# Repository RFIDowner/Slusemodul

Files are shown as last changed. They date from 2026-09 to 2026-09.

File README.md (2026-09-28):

# Slusemodul

Modulær duesluse for PigeonPal: duene går én og én over innebygde 125 kHz RFID-spoler, slik at hver chipring leses sikkert ved hjemkomst. Alle deler printes i PETG på Bambu Lab A1 (maks 256 × 256 × 256 mm).

## Versjoner

| Versjon | Hva | Status |
|---|---|---|
| **v4.3** | **Kabelføring, kortfeste, skyvelokk løftet 4 mm, leser i tørt rom, gafler med nav** | **Gjeldende – STL og STEP klar** |
| v4.2 | Som v4.1, men 8-kantede gafler som hviler mot karkanten. Terskelstangen er fjernet. | Erstattet av v4.3. Karet er printet. |
| v4.1 | Som v4, men vegger og tak er én hette. To print totalt. | Erstattet av v4.2 |
| v4 | Ett kar (200 mm): forgang med elektronikk + rett spole, gafler, klikk-feste | Erstattet av v4.1 (kar, lokk og gafler er like) |
| v3 | Tre moduler A–M–B med svalehaleskjøt (rett spole + diamantspole) | Erstattet av v4. Modul B er printet. |
| v2 | Ett kar med to spoler og sidekammer | Kun tegning |
| v1 | Første tegning, én diamantspole | Kun tegning |

Hvorfor v4: diamantspolen i v3 er 141 mm lang langs løpet, så to duer kunne stå i lesesonen samtidig. Den rette spolen er 100 mm, og forgangen foran holder neste due utenfor lesesonen.

## v4.3 – gjeldende modell

Erfaring fra v4.2-printen: klikk-nesene som holder spolen er perfekte og er uendret. Endringene:

- **Lokket** under el-rommet er løftet 4 mm over brettet, så det aldri står i vann. Det skyves inn fra inngangsenden i spor (kile under og skinne over, begge med 45° så de printes uten støtte) og låses med en klikk-tunge bak endeveggen. Fingerhull Ø7 i tungen: løft tungen og dra. Tre dreneringsslisser ved skilleveggen. Ingen skruer, ingen pakning.
- **Leseren** (35 × 15 × 1 mm) sitter i tørt rom, i en holder i hjørnet ved skilleveggen. Den skyves inn mot skilleveggen og holdes av en liten kul. Kabler ut i begge ender.
- **Skilleveggen** har to slisser, begge åpne nedenfra: 2 mm sprekk for spoletrådene rett foran leserens ende, og 5 mm slisse for strømkabelen. Tettes med Sika etter at kablene er lagt. Det er de eneste åpningene inn i el-rommet.
- **Strømkabelen** kommer inn under sideveggen gjennom en slisse 5 × 6 mm i underkanten, rett etter skilleveggen. PG7-hullet er borte.
- **PigeonPal-PCB** henger under gulvet på tre avstandsklosser med styretapper i H4, H3 og H1 (mål fra KiCad-filen), og holdes av to fjærende kroker. Komponentsiden vender ned mot lokket. Pluggkanten (J9, J3, J4) vender mot −y med 55 mm fri plass foran pluggene. Bøy krokene ut for å ta av kortet.
- **Gaflene** har en 8-kantet nav på 21 mm langs akselen. Fem naver fyller 105 av 110 mm, så de holder avstanden selv med 1 mm mellom hver. Stangen ligger flush med navet på utsiden, så gaffelen ligger flatt i printen.
- **Fjernet:** ribbene under leseren (107 mm broer i printen, ingen funksjon) og det blinde Ø6-hullet i skilleveggen.
- Slissene for veggtappene har runde ender.

| Print | Fil | Mål på platen |
|---|---|---|
| 1 | `stl/v4.3/sluse_v4.3_print1_kar_og_gafler.stl` – kar (gulvet ned) + 5 gafler | 200 × 239 × 32 mm |
| 2 | `stl/v4.3/sluse_v4.3_print2_hette_og_lokk.stl` – hette (taket ned) + lokk (oversiden ned) | 200 × 230 × 133 mm |

Sammenstillingen `step/v4.3/sluse_v4.3_sammenstilling.step` har kortet, leseren, spolen og akselen som referanser. Bilder i `tegninger/v4.3/`. Generator: `generator/sluse_v4_3_step.py`.

Ikke testet på print: lokkets spor (0,3 mm klaring), klikk-tungen, krokene på kortet og leserholderen (0,15 mm kul).

## v4.2 – 8-kantede gafler mot karkanten (erstattet av v4.3)

Som v4.1, med to endringer i utgangen:

- **8-kantede gafler**, 6 mm over flatene, med et rundt øye (Ø9) rundt akselen. De printes liggende på en flate, uten støtte.
- **Karkanten er stopperen.** Akselen står der den var (x = 188, 116 mm over gulvet). Gaflene henger ca. 7° på skrå fra akselen og ut over karets endekant. Endekanten har en skråflate (1,2 mm inn i toppen, 10 mm ned) som gaflene ligger flatt mot. Gaflene går 2 mm lenger ned enn skråflaten. Terskelstangen er fjernet.
- Kontrollert i modellen: gaflene stopper mot karet med en gang de dyttes utover, og kan svinge ca. 80° innover i slaget før de treffer taket.

| Print | Fil | Mål på platen |
|---|---|---|
| 1 | `stl/v4.2/sluse_v4.2_print1_kar_og_gafler.stl` – kar (gulvet ned) + 5 gafler | 200 × 219 × 32 mm |
| 2 | `stl/v4.2/sluse_v4.2_print2_hette_og_lokk.stl` – hette (taket ned) + lokk | 200 × 227 × 133 mm |

Bilder: `tegninger/v4.2/`. Generator: `generator/sluse_v4_2_step.py`.

## v4.1 – vegger og tak som én hette (erstattet av v4.2)

Samme kar, lokk, gafler og terskelstang som v4. Endringen er at begge veggene og taket er smeltet sammen til **én hette**. Den printes opp-ned: taket ligger på platen og veggene står rett opp.

| Print | Fil | Mål på platen |
|---|---|---|
| 1 | `stl/v4.1/sluse_v4.1_print1_kar_og_gafler.stl` – kar (gulvet ned) + 5 gafler + terskelstang | 200 × 224 × 32 mm |
| 2 | `stl/v4.1/sluse_v4.1_print2_hette_og_lokk.stl` – hette (taket ned) + lokk | 200 × 227 × 133 mm |

- Hetta klikkes ned i karet med de samme tre tappene per vegg som i v4. Klikket mellom tak og vegg er borte.
- Veggfoten er 12 mm bred (var 20 mm) med 45° skråkant, slik at den kan printes uten støtte når hetta står opp-ned.
- Hetta er 133 mm høy på en bedslinger. U-formen er stivere enn to løse vegger, men bruk gjerne brim og litt lavere hastighet på yttervegg.
- Delene finnes også hver for seg i `stl/v4.1/` og `step/v4.1/`, og samlet i `step/v4.1/sluse_v4.1_sammenstilling.step`.
- Bilder: `tegninger/v4.1/`. Generator: `generator/sluse_v4_1_step.py`.

Ikke testet på print ennå: klaringene på klikk-tappene. Mothaken på tappene har en 0,9 mm flat kant som blir et lite overheng i print 2, men det er for kort til å trenge støtte.

## v4 – ett kar, løse vegger og tak (erstattet av v4.1)

Ett kar på 200 × 150 mm, gulvet 32 mm over landingsbrettet:
- **Forgang (0–90 mm):** elektronikkammer under gulvet. Lokk fra undersiden med fire M3-skruer og spor for Ø2 silikonsnor. Hull i sideveggen for PG7-kabelnippel.
- **Leser (90–200 mm):** rett 10 × 10 cm-spole i lomme under 4 mm gulv. Spolen presses opp nedenfra, og fire fjærende klikk-neser holder den. Kabelen går inn i kammeret gjennom et hull høyt i skilleveggen.
- **Gafler i utgangen:** fem Ø6 × 116 mm som henger til 3 mm over gulvet mot en terskelstang på slusesiden. De svinger bare innover.
- **Klikk-feste uten skruer:** veggene har tre tapper hver ned gjennom gulvet i spoledelen. Taket klikker inn i et spor på utsiden av veggenes topplist.

| Fil | Innhold |
|---|---|
| `stl/v4/` | Kar, lokk, vegg høyre/venstre, tak, gafler + terskel. Print-orientert, ingen støtte. |
| `step/v4/` | Samme deler i montert posisjon, og `sluse_v4_sammenstilling.step` med alt samlet (inkl. spole og aksel som referanse). |
| `tegninger/v4/` | Bilder av montert modell og undersiden. |
| `generator/sluse_v4_step.py` | Lager alle v4-filene (krever `pip install cadquery`). |

Kjøpedeler: aksel Ø3 × 130 mm rustfri, Ø2 silikonsnor, 4 × M3 × 8 mm skruer til lokket.

Ikke testet på print ennå: klaringene på klikk-festene (standardverdier for PETG) og at klikk-nesene passer spolen (dimensjonert for nøyaktig 100 × 100 mm ytre mål).

Mulig endring senere: la gaflene henge utenfor karets endevegg, slik at karkanten blir stopperen og terskelstangen kan fjernes.

## v3 – tre moduler (erstattet av v4)

Slusa består av tre moduler som skyves sammen ovenfra med svalehaleskjøt:

| Modul | Lengde | Innhold |
|---|---|---|
| **A** – inngang | 110 mm | Rett 10 × 10 cm-spole, trådene på tvers av løpet |
| **M** – midt | 90 mm | Elektronikkammer under gulvet (PigeonPal-PCB + to lesermoduler), lokk fra undersiden |
| **B** – utgang | 150 mm | Diamantspole (dreid 45°) + bobs som bare svinger innover |

- Løpet er 110 mm innvendig bredde og 120 mm åpningshøyde. Gulvet ligger 32 mm over landingsbrettet.
- Vegger og tak er spiler, så slusa er gjennomsiktig og ikke oppleves som en tunnel.
- De to spolene har ulik orientering (rett og diamant), så de feiler på forskjellige ringvinkler. Det gir reell redundans, ikke bare dobbelt opp.
- Rekkefølgen A → B gir retning. Firmware dedupliserer samme chip-ID fra begge portene (J3/J4).
- Elektronikken ligger i en modul uten spole, minst ca. 5 cm fra nærmeste vikling.

Bakgrunnen for høydevalget (ring 9–14 mm over viklingen, ikke 5–10 cm) står i [`analyse/coil-hoyde-rapport.md`](analyse/coil-hoyde-rapport.md).

## Status (v3-deler)

| Del | Status |
|---|---|
| Modul B – kar med diamantlomme | STL klar, testprint pågår |
| Modul B – veggpanel høyre/venstre | STL klar |
| Modul B – takpanel | STL klar |
| Modul B – bobs, stoppstang, sperrelister | ikke laget ennå |
| Hele v3 (A + M + B) som STEP, tre bodies | klar |
| v4 – ett kar, klikk-feste, gafler | STL og STEP klar |
| Modul A og M – printbare delfiler | ikke laget ennå |
| Klikk-/snapp-feste i stedet for skruer | planlagt |

## Mapper

- `stl/modul_B/` – ferdige STL-filer, allerede lagt i print-orientering (ingen støtte).
- `step/` – STEP-filer til Fusion, i montert posisjon:
  - `sluse_v3_komplett_3_bodies.step` – hele slusa, der A, M og B er hver sin body (kar, vegger og tak smeltet sammen per modul).
  - `sluse_v3_modul_*.step` – én modul per fil.
  - `step/modul_B/` – modul B delt opp i de fire delene som printes (kar, vegg høyre/venstre, tak), og en sammenstilling.
- `generator/` – Python-skript som lager STL-ene. Alle mål er parametre øverst i hver fil.
- `tegninger/v1…v3/` – tekniske tegninger (SVG/PNG) og skriptene som lager dem.
- `analyse/` – rapport om spolehøyde og lesesikkerhet, med Biot–Savart-modellen av spolen.

## Lage STL på nytt

```bash
pip install manifold3d numpy
python generator/modul_B_kar.py
python generator/modul_B_vegg.py
python generator/modul_B_tak.py
```

STL-ene skrives til `stl/modul_B/`. STEP-filene lages med `generator/modul_B_step.py` og `generator/sluse_v3_step.py` (krever `pip install cadquery`). Forhåndsvisninger (SVG) havner i samme mappe, men holdes utenfor git.

## STEP i Fusion

- **Som eget design:** File → Open → Open from my computer → velg `.step`.
- **Inn i et design du jobber med:** last opp filen i Data Panel, høyreklikk den og velg **Insert into Current Design**.
- Modellene kommer inn som solider uten parametre. Bruk Press/Pull, skisser og Combine for å endre dem.

## Print-innstillinger (PETG, A1)

- 0,20–0,28 mm lag, 2 vegger, 10–15 % infill.
- Skjørt, ikke brim.
- Ingen støtte: alle deler er orientert slik at hulrom og lommer åpner oppover.
- Legg inn raskere hastigheter enn Generic PETG-profilen, for eksempel yttervegg 120 mm/s og indre vegg 200 mm/s.

## Kjøpedeler

- Bobs-aksel: Ø3 × 150 mm, rustfri eller messing. Ikke vanlig stål nær spolene.
- Treskruer 3,5 × 25 mm til veggføtter og feste mot landingsbrettet.
- Skruer 3 × 12 mm til takpanel.
- Kabelnippel eller Ø2 silikonsnor til pakning i modul M.

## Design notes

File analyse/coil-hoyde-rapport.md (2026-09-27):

# Chipring-lesing i duefelle: lav eller hevet spole?

## 1. Kort svar

**Ikke bygg forhøyningen.** Monter spolen rett under et tynt gulv slik at ringen passerer 0,5–2 cm over viklingen (alternativ A). Det er teoretisk klart sterkest, og konklusjonen A > B gjelder uansett hvilken vei transponderaksen i ringen peker. Å legge spolen 5–10 cm under fuglen (alternativ B) flytter ringen til den delen av feltet der du målte *maks* rekkevidde på benken, dvs. null margin: 8–10 cm er lesegrensen for beste orientering på spoleaksen, ikke en driftshøyde. For en ring med horisontal transponderakse er 7–10 cm under terskel for alle ringrotasjoner (0,36–0,80× terskel i modellen), og 5 cm er marginalt. Det beste svaret er likevel ikke bare "lavt", men "lavt pluss riktig spolegeometri", se punkt 4.

## 2. Teorien, punkt for punkt

Alle tall er fra en Biot–Savart-modell av din 10 × 10 cm luftspole (ren Python, `coil_field_biot_savart.py` i denne mappen), verifisert mot lærebokformelen for senterfeltet (2√2·μ0·I/(π·a) = 11,31 µT per ampere-vikling). Terskelen er kalibrert fra din benketest: B_thr = feltet på aksen ved 9 cm = 14,6 % av senterfeltet. Absoluttverdiene skalerer med N·I; alle *forhold* (marginer, lesbar lengde) er uavhengige av det.

**a) Feltstyrke mot høyde.** På aksen er feltet nesten flatt så lenge høyden er mye mindre enn halvbredden (5 cm): 99 % av senterverdien ved 0,5 cm, 95 % ved 1 cm, 83 % ved 2 cm, 68 % ved 3 cm, 41 % ved 5 cm, 24 % ved 7 cm, 19 % ved 8 cm, 11,5 % ved 10 cm, deretter mot 1/z³ (Microchip AN678: feltet faller som r⁻³ og er hovedbegrensningen for rekkevidde). Ved 0,5–1 cm ligger vertikalfeltet 6,5–6,8× over terskelen (ca. 16 dB; 5,1–5,3× hvis reell grense er 8 cm). Ved 5–10 cm er du på den delen av kurven som faller med eksponent −1,6 (5–7 cm), −1,9 (7–8 cm) og −2,1 (8–10 cm), på vei mot −3. AN678/AN710s optimumsregel (sløyferadius ≈ 1,414 × leseavstand) sier bare at ved 8–10 cm ville en 14–28 cm bred sløyfe gitt mer felt per ampere-vikling; 10 cm-spolen leser der (det viser testen din), men den jobber utenfor sitt optimum, uten margin.

**b) Feltretning mot høyde og sideveis posisjon.** Inne i sløyfen nær overflaten er feltet vertikalt; rett over en leder er det horisontalt og sirkulært rundt tråden (≈ μ0·N·I/(2π·d), 1/d-lov). Rett over spolens senter er horisontalkomponenten *eksakt null i alle høyder* (symmetri). Feltets helning fra vertikal rett over tråden: 84° ved 0,5 cm, 78° ved 1 cm, 67° ved 2 cm, 59° ved 3 cm, 48° ved 5 cm, 40° ved 7 cm, 33° ved 10 cm. Jo høyere du går, desto mer *vertikalt* blir feltet også over trådene, og horisontalmaksimum flytter seg utover (5,5–6,5 cm fra senter ved 7–10 cm) og krymper til ~0,5× aksefeltet i samme høyde. Høyde gir altså ingen orienteringsgevinst for en fotring; forholdet horisontal/vertikal er låst til ~0,5 for alle høyder ≥ 3 cm.

**c) cos-θ-kobling og fotringen.** Indusert spenning i tag-spolen er V = 2πf·N·S·Q·B·cos α (AN678/AN710): bare feltkomponenten *langs transponderaksen* teller. Hvor aksen peker inne i ringen er avgjørende:
- *Horisontal akse* (typisk Hitag S-modul 8 × 10 mm i "knollen", radial eller tangential): ringen kobler kun til horisontalfeltet, som finnes bare nær lederne. Dette er det PIT-/fiskeri-litteraturen kaller "pass-over"-geometri: taggen leses best rett over tråden, rekkevidden er kortere enn "pass-through", og to separate deteksjoner per passering er mulig (Oregon RFID; LF 125 kHz-studien av steinsporing: "i vinkelrett konfigurasjon er deteksjonen svak, taggen kan bare detekteres over antennens kanter"). Ringen roterer fritt rundt beinet, så azimut er tilfeldig per passering. En ring hvis akse tilfeldigvis står *på tvers* av gangretningen og går nøyaktig på midtlinjen ser By = 0 i alle høyder. Det er et geometriproblem, ikke et høydeproblem.
- *Vertikal akse* (spole viklet rundt ringens omkrets, jf. EP2036001): ringen kobler til vertikalfeltet, hele sløyfeinteriøret er lesesone, og benketesten er direkte representativ.
- Beinet (tarsometatarsus) står ikke loddrett, anslagsvis 20–40° fra vertikal i stående stilling og mer under steget. Med 30° helning får en "horisontal-akse"-ring en Bz-kobling på ca. 0,5·Bz, som i praksis fjerner azimut-nullet i alternativ A, gjør 5 cm marginalt lesbart for alle rotasjoner og lar 7–10 cm forbli under terskel.

**d) Margin: dypt inne i feltet vs. nær maks rekkevidde.** Realistisk minsteavstand transponder–leder er 1–2 cm (viklingsbunt 2–5 mm + gulv 3–10 mm + knollens høyde over sålen), 1,5–3 cm i standfasen og 3–5 cm i svingfasen. 0,5 cm-raden under er en teoretisk grense, ikke driftspunktet. Overkobling/detuning ved lav høyde er ikke et problem for en mm-stor fotringtransponder: k ≈ 0,01 over tråden mot kritisk kobling k_c = 1/√(Q1·Q2) ≈ 0,05, dvs. ≥ 4× underkoblet, ingen frekvenssplitting (PMC5017394). Både energioverføring og lastmodulasjon tilbake til leseren skalerer med samme gjensidige induktans, så nærmere ring forbedrer begge samtidig.

| Avstand ring–vikling | Vertikal akse: margin på aksen | Vertikal akse: lesbar lengde av 18 cm | Horisontal akse, beste rotasjon: margin over leder | Horisontal akse, verste rotasjon m/ 30° beinhelning | Horisontal akse, beste rotasjon: lesbar lengde |
|---|---|---|---|---|---|
| 0,5 cm (teoretisk) | 6,8× | hele | 24× | – | 9 cm (to bånd) |
| 1 cm | 6,5× | hele | 11,8× | 4,5× | 11 cm (to bånd) |
| 2 cm | 5,7× | 13,5 cm | 5,5× | 2,9× | 14 cm |
| 3 cm | 4,7× | 11,5 cm | 3,3× | 2,3× | 14 cm |
| 5 cm | 2,8× | 11,5 cm | 1,5× | 1,4× | 11 cm |
| 7 cm | 1,65× | 9,5 cm | 0,80× | 0,8× | 0 |
| 8 cm | 1,28× | 7,5 cm | 0,61× | – | 0 |
| 10 cm | 0,79× | 0 | 0,36× | – | 0 |

Ved 0,5–1 cm er lesesonen for horisontal akse *to* 4,5–5,5 cm brede bånd sentrert på de to tverrtrådene (ca. 2,6–7,6 cm fra senter ved 1 cm), med et null over senteret. Gangbane 2,5 cm ut av senter gir lengre lesbar sone (opptil 17,5 cm ved 2–3 cm) fordi sidetrådene bidrar med By. Forhold lav/høy for horisontal akse: 1 cm mot 5/7/8/10 cm = 7,8× / 15× / 20× / 33×, dvs. 18–30 dB kastet bort uten noen orienteringsgevinst. Ved 7–10 cm er beste horisontalfelt 0,36–0,80× terskelen; med modellens usikkerhet (±1,27×) er 7 cm "ikke pålitelig", 8–10 cm "ikke lesbar". Ved 5 cm faller omtrent halvparten av ringrotasjonene under terskel uten beinhelning.

**e) Oppholdstid og telegramrepetisjon.** EM4100/TK4100 sender 64 bit kontinuerlig ved RF/64: 64 × 512 µs ≈ 33 ms per telegram, ≤ 66 ms sammenhengende felt garanterer ett komplett telegram (RDM6300 leverer pakke hvert ~65 ms). Er leseren en RDM6300/EM4100-modul, er ringene EM4100/TK4100-kompatible; Hitag S (kommandostyrt, T0 = 8 µs, anslått samme størrelsesorden fra T0/twsc, ikke målt full lesesyklus) gjelder da ikke. Duer på tredemølle er kjørt ved 0,20–0,40 m/s (JEB 209:292); løp begynner rundt 0,75–0,9 m/s (Gatesy & Dial 1993; Fujita 2002). Men gangen er ikke jevn: foten står stille i standfasen (~0,25 s) eller svinger 2–4 cm over gulvet i ~0,15–0,2 s, ca. dobbelt så fort som kroppen. Med ett 10 cm-kvadrat og to lesebånd 10 cm fra hverandre er det grovt ~1/3 sjanse for at ingen stans havner i et bånd (horisontal akse); da må ringen leses i svingfasen ved 3–4 cm (2–3× margin, 60–80 ms = 1–2 EM4100-telegram, knapt for en Hitag S-handshake). Tid er ikke flaskehalsen, men sammenhengende lesesoner (vertikal akse, figur-8 eller flere ledere på tvers) er å foretrekke, nok et argument mot forhøyning.

**f) Kommersiell praksis.** Benzing G2 (15 × 19 cm per felt), Bricon (1–6 felt) og Unikon ("two-field pad") er flate flerfeltspader i 22–27 mm tykke hus, montert i eller under ≤ 15 mm kryssfiner (Bricon); ringen passerer derfor typisk 2–4 cm fra viklingen, innenfor sonen der modellen gir 3–5× margin, aldri 5–10 cm. FCI krever sikker lesing innenfor 5 cm. At Bricons "5–7 cm"-test er en marginkontroll med håndholdt ring og ikke driftshøyde, er vår tolkning, ikke leverandørens ord.

## 3. Hva benketesten sier, og ikke sier

Den sier hvor terskelen ligger for beste orientering (≈ 0,12–0,19 × senterfeltet) og at leser + spole + ring fungerer. På spoleaksen er feltet rent vertikalt. At ringen leses på aksen ved 8–10 cm betyr derfor at transponderaksen hadde en vesentlig vertikal komponent *i testorienteringen*. Hvordan holdt du ringen?

- Holdt du den **flatt, slik den sitter på beinet** (ringplanet parallelt med spolen): da er aksen vertikal på fuglen, benketesten er direkte representativ, og Bz-kolonnen gjelder. A gir 6–9× margin over hele sløyfen; B ved 5 cm gir 2,8× og fungerer, men 7,7 dB dårligere og uten reserve for høydevariasjon; 8 cm 1,28×, 10 cm ingen lesing. Figur-8/skjevstilling er da ikke nødvendig.
- Holdt du den **på høykant / med knollen flatt** (aksen horisontal på beinet): da gjelder kant-/pass-over-analysen, og geometrivalg i punkt 4 blir nødvendig, ikke valgfritt.

Testen sier ikke noe om gangfart, beinhelning, ringrotasjon eller om foten faktisk krysser en leder. Bruk 8–10 cm kun som terskelreferanse, aldri som driftshøyde.

## 4. Anbefaling, rangert

**Felles for alle:** spole rett under gulvet. 3–10 mm PETG er fint (Bricon tillater 15 mm kryssfiner); det som teller er total avstand ring–vikling ≤ 2–3 cm. Ingen metall, folie, netting eller karbonfylt plast mellom spole og fot (skinndybde 0,2–0,26 mm i Cu/Al ved 125 kHz gir titalls dB skjerming pluss detuning). Spolen bør være minst like bred som gangbanen (10–12 cm), så enten 12–14 cm sløyfe eller to sløyfer side om side. Lag et kort kanalløp så fuglen må *gå* over spolen, ikke hoppe; hopp over paden er den vanligste feilårsaken i praksis. Hold leser og evt. andre 125 kHz-spoler ≥ 1 m fra hverandre.

1. **Lav montering + ledere langs OG på tvers av gangbanen** (høyest sikkerhet, middels innsats). Kvadratisk sløyfe kombinert med en langsgående figur-8 (byttet/multiplekset, eller to leserkanaler): verste-azimut-margin 10,8× / 5,0× / 3,0× ved 1/2/3 cm. Alternativt kvadrat + liten vertikal veggspole (akse på tvers av passasjen) for tverr-azimuten. Merk: figur-8 med felles midtleder *på tvers* dobler feltet over midtlederen (79/39/18/11/5 µT per A-vikl. ved 0,5/1/2/3/5 cm, ved lik strøm per sløyfe) og flytter nullet til ytterkantene, men fjerner ikke tverr-azimut-nullet på midtlinjen. Induktansen omtrent dobles, så ved samme drivspenning blir gevinsten mindre og leseren må tunes på nytt. Patent 5602556 (figur-8 gir felt parallelt med antennen) og 8558751 (dobbel sløyfe med alternerende fase mot orienteringsvarians, 125 kHz) beskriver prinsippet.
2. **Lav montering + én sløyfe dreid 45° ("diamant") eller 15–30° skjev**, minst tre ledere på tvers av banen (best nytte/innsats). Diamant: verste-azimut 7,9× / 3,2× / 1,7× ved 1/2/3 cm for et bein 2 cm fra midten, 4,1× / 1,1× / 0,5× 0,5 cm fra midten og null eksakt på midtlinjen, men 5,3× / 3,0× / 2,3× også på midtlinjen med 30° beinhelning. Chipringen sitter på ett bein ca. 1–1,5 cm fra kroppens midtlinje, og fuglen vandrer, så midtlinje-nullet er lite i praksis, men ikke null. Forskyvning 2,5 cm fra midtlinjen gir tverr-azimut-dekning, men bare 0,8× / 1,4× / 1,8× / 1,6× margin ved 0,5/1/2/3 cm, ikke tilstrekkelig alene.
3. **Lav montering + én kvadratisk sløyfe sentrert, trådene på tvers** (enklest). To 4,5–5,5 cm brede lesebånd med 9–12× margin (beste rotasjon), men ~5–15 % av rotasjonene bommer på midtlinjen ved 0,5–2 cm, og ~1/3 av passeringene får ingen stans i et bånd. Godt nok hvis aksen viser seg å være vertikal.
4. **Vertikal portalsløyfe fuglen går gjennom**, ca. 12 × 18 cm: svært høydetolerant (10 × 10-modellen ga 45/25/15,5/12,7/11,3 µT per A-vikl. ved 0,5–5 cm over gulvet) og orienteringsrobust for akse langs gangretningen; mer mekanikk og trenger sidespole for tverr-aksen.
5. **Forhøyet gangbane, spole 5–10 cm under (B):** dårligst. Horisontal akse: null lesing ved ≥ 7 cm, marginalt ved 5 cm. Vertikal akse: 2,8× ved 5 cm, 1,28× ved 8 cm, ingen ved 10 cm, alt uten reserve for høydevariasjon. Ikke anbefalt.

## 5. Benketest du kan gjøre i kveld

**Test 0 (5 min, avgjør aksen):** sett ringen på en vertikal pinne nøyaktig som på beinet (ringplanet horisontalt). Senk den til 1 cm over spolens *senter* og over en *kanttråd*. Leser bare over kanten → horisontal akse, punkt 4.1–4.2 er nødvendig. Leser best over senter → vertikal akse, punkt 4.3 holder.

**Test 1 (høydeskann):** samme pinne, beveg ringen horisontalt tvers over spolen i fast høyde 0,5 / 1 / 2 / 3 / 5 / 8 cm over viklingen, sentrert bane og bane 2,5 cm ut av senter. Noter hvor den leser. Gjenta med ringen rotert 0°, 45° og 90° om pinnen.

Forventet (horisontal akse): ved 0,5–1 cm to smale bånd (4–6 cm) over trådene, null i midten; ved 2–3 cm bredere men svakere bånd; ved 5 cm sporadisk, avhengig av rotasjon; ved 8 cm ingenting. Forventet (vertikal akse): lesing over hele sløyfen ved 0,5–3 cm, krympende mot 7–8 cm, ingenting ved 10 cm. Forskjøvet bane bør gi lengre lesesone ved 1–3 cm.

**Det som bekrefter anbefalingen:** sikker lesing ved 1–3 cm (over trådene eller hele flaten) og tap ved 5–8 cm. **Det som velter den:** sikker lesing i alle rotasjoner ved 5–8 cm og *ikke* ved 1–2 cm; da er enten viklingen mye bredere/spolen tunet slik at nærsonen overkobler (front-end-problem, løses med Q/tuning), eller premissene om ringen er feil, og vi må se på den på nytt.

**Etter bygging:** test med aluminiums-forbundsringen montert som på fuglen, og logg med levende fugl i gangfart, ikke bare ringen på pinne; fotplassering i standfasen er den gjenværende feilkilden. Krav: sammenhengende lesing over ≥ 4 cm i alle rotasjoner ved faktisk gulvhøyde.

## 6. Usikkerheter

- Transponderaksen i ringen er ukjent; Test 0 avgjør. A > B holder i begge tilfeller, men geometrikravene avhenger av det.
- Modellen er en filamentær enkeltvikling i luft, uten gulv-/kroppstap. 40 µT-toppen ved 0,5 cm er overestimert for en flere mm bred viklingsbunt; verdiene ved 1–3 cm er robuste. En bunt av bredde w flater ut 1/d-loven for d < w.
- Terskel kalibrert til 9 cm; 8 cm krymper alle marginer 1,28×, 10 cm øker dem 1,26×. Ingen konklusjon endres.
- Beinhelning (20–40°), ringens vagging, eksakt beinhøyde over gulvet og stegmønster er antatt, ikke målt.
- Transpondertype (EM4100 vs Hitag S) påvirker telegramtid og H_min, ikke høydetrenden. Hitag S-timing er et estimat fra datablad-utdrag.
- Leserens følsomhet, Q og AGC kan gi egne nærsone-effekter; det er et front-end-problem, ikke et høydeproblem.
- Ingen sitater kunne verifiseres mot originaldokumentene i denne kontrollen (nettsperre); ordlyd fra Microchip, Oregon RFID, patenter, Bricon/Benzing/Unikon, FCI og tidsskrifter bør sjekkes mot PDF-ene før den siteres videre.

## 7. Kilder

- [Microchip AN678, RFID Coil Design](https://ww1.microchip.com/downloads/en/appnotes/00678b.pdf) – r⁻³-fall, cos α-kobling, optimumsregel for sløyferadius
- [Microchip AN710, Antenna Circuit Design for RFID Applications](https://ww1.microchip.com/downloads/en/appnotes/00710c.pdf)
- [Microchip DS51115, microID 125 kHz Design Guide](https://ww1.microchip.com/downloads/en/devicedoc/51115f.pdf)
- [OpenStax, Magnetic Field of a Current Loop](https://phys.libretexts.org/Bookshelves/University_Physics/University_Physics_(OpenStax)/University_Physics_II_-_Thermodynamics_Electricity_and_Magnetism_(OpenStax)/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) – Biot–Savart, aksefelt
- [IntechOpen, LF/HF RFID coupling and H_min](https://www.intechopen.com/chapters/57275)
- [Finkenzeller, RFID Handbook, 3. utg.](https://www.wiley.com/en-us/RFID+Handbook:+Fundamentals+and+Applications+in+Contactless+Smart+Cards,+Radio+Frequency+Identification+and+Near+Field+Communication,+3rd+Edition-p-9780470695067)
- [Oregon RFID, Antenna types (pass-over vs pass-through)](https://www.oregonrfid.com/resources/antenna-types/)
- [Biomark PIT-tag antennas](https://www.biomark.com/pit-tag-antennas/) og [AFS/Biomark antenner](https://units.fisheries.org/fits/solution/fish-tracking/rfid/biomark-antennas/)
- [NOAA, PIT-antenne feltgeometri](https://repository.library.noaa.gov/view/noaa/50485/noaa_50485_DS1.pdf)
- [Zentner et al. 2021, PIT-antenne deteksjon vs orientering](https://agriculture.okstate.edu/departments-programs/natural-resource/research/natural-resource-labs/shoup-fisheries-management-and-fisheries-ecology-lab/zentner_et_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)
- [Pebbles tracking with LF RFID multi-loop reader (kantdeteksjon i vinkelrett orientering)](https://www.researchgate.net/publication/270337982_Pebbles_Tracking_Thanks_to_RFID_Lf_Multi-Loops_Inductively_Coupled_Reader) / [HAL](https://centralesupelec.hal.science/hal-01104660)
- [US 5602556, figur-8-sløyfe med felt parallelt med antennen](https://image-ppubs.uspto.gov/dirsearch-public/print/downloadPdf/5602556)
- [US 8558751, dobbel sløyfe med alternerende fase, 125 kHz](https://image-ppubs.uspto.gov/dirsearch-public/print/downloadPdf/8558751)
- [PMC5017394, kritisk kobling og frekvenssplitting](https://pmc.ncbi.nlm.nih.gov/articles/PMC5017394/)
- [EP0884700B1, Deister/Unikon flerfelts duepad](https://patents.google.com/patent/EP0884700B1/en)
- [EP2036001B1, transponder-fotring for duer](https://patents.google.com/patent/EP2036001B1/de)
- [FCI, krav til elektronisk konstatering](https://img.pigeonsfci.net/uploads/files/20241104/87de9a8ee1972ad0ccb38cbf030db2be.pdf)
- [Benzing G2 antenne](https://www.benzing.cc/benzing-g2-antenna/) og [Benzing antennepader](https://www.benzinguk.com/product-category/antenna-pads/)
- [Bricon Speedy manual](https://www.bricon.be/uk/manuals/Speedy%20UK-14.pdf) / [manualslib](https://www.manualslib.com/manual/1304348/Bricon-Speedy.html)
- [Unikon loft-system](https://www.unikon.co.uk/loft/) og [Unikon manual](http://www.unikon-usa.com/us/files/unikon_manual_010307.pdf)
- [Hitag S256 duefotring](https://zdcard.en.made-in-china.com/product/pSImxjvKbuYM/China-RFID-Racing-Pigeon-Foot-Ring-Hitag-S256-for-Tauris-Ets-Clocking-System.html)
- [EM4100 datablad](https://download.mikroe.com/documents/accessories/rfid/125khz/rfid-card-125khz-em4100-datasheet.pdf) og [EM4100-protokoll](https://www.priority1design.com.au/em4100_protocol.html)
- [RDM6300 (Tasmota-dok.)](https://tasmota.github.io/docs/RDM6300/)
- [NXP Hitag S datablad](https://media.digikey.com/pdf/Data%20Sheets/NXP%20PDFs/HTS.pdf)
- [J. Exp. Biol. 209:292, duer på tredemølle 0,20–0,40 m/s](https://journals.biologists.com/jeb/article/209/2/292/16277/Influence-of-the-behavioural-context-on-the)
- [Skinndybde-kalkulator](https://www.firgelliauto.com/blogs/engineering-calculators/skin-depth-calculator) og [RFID-skjerming](https://rfid4u.com/rfid-shielding-and-blocking-materials/)
- [pigeons.biz, installasjon av elektronisk klokke](https://www.pigeons.biz/threads/electric-clock-installation.65274/)

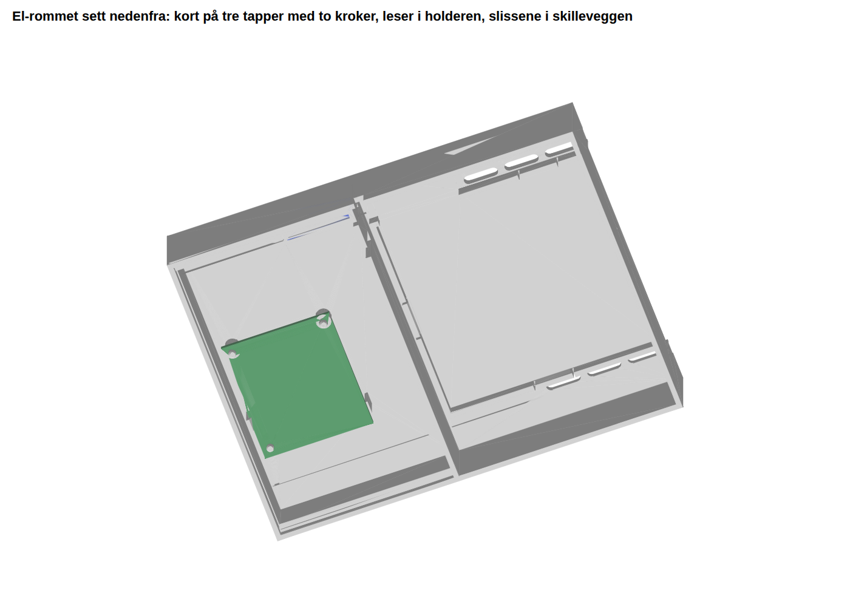
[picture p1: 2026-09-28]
tegninger/v4.3/sluse_v4.3_kammer_naerbilde.png

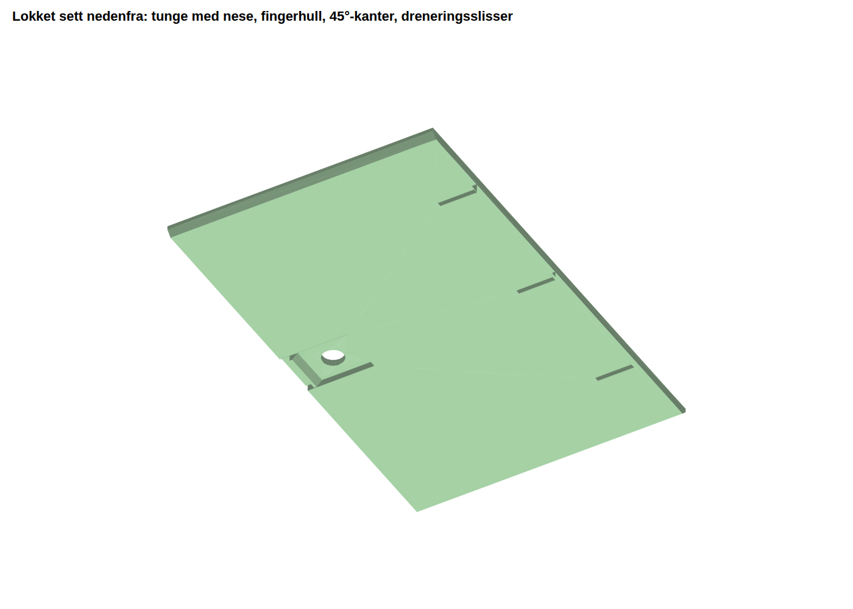
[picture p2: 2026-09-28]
tegninger/v4.3/sluse_v4.3_lokk.png

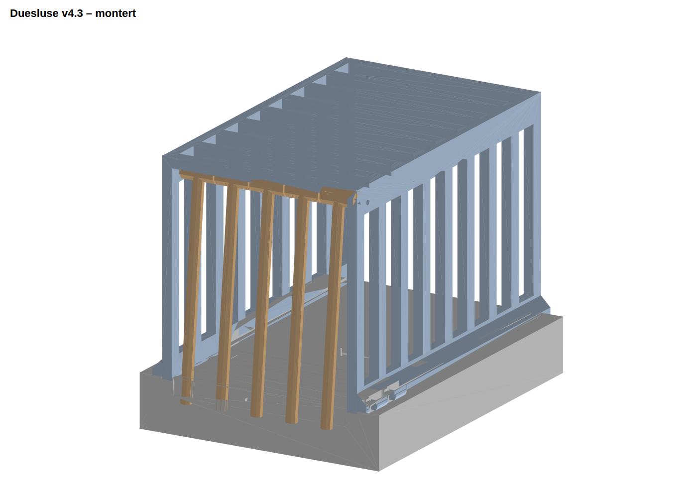
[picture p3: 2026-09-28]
tegninger/v4.3/sluse_v4.3_montert.png

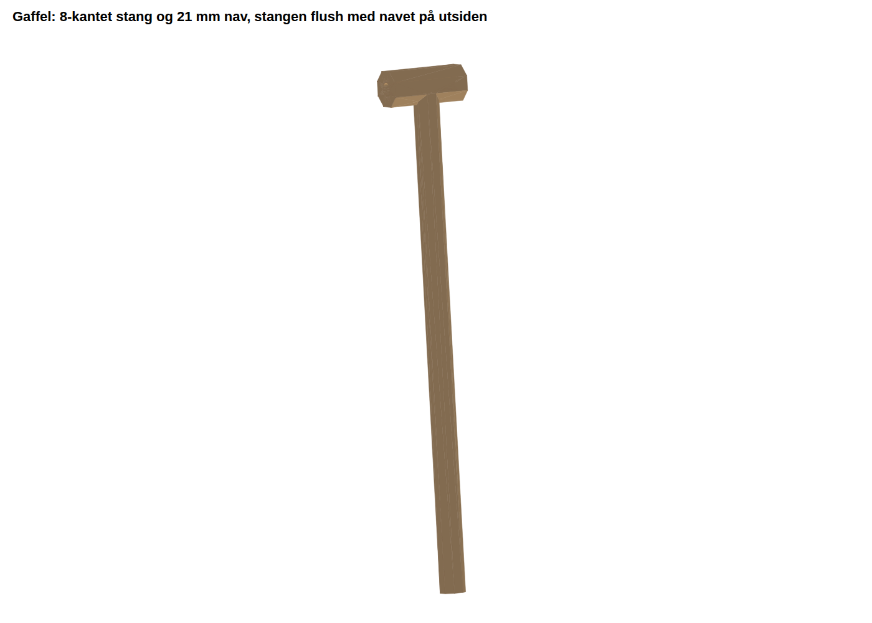
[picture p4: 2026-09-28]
tegninger/v4.3/sluse_v4.3_gaffel.png

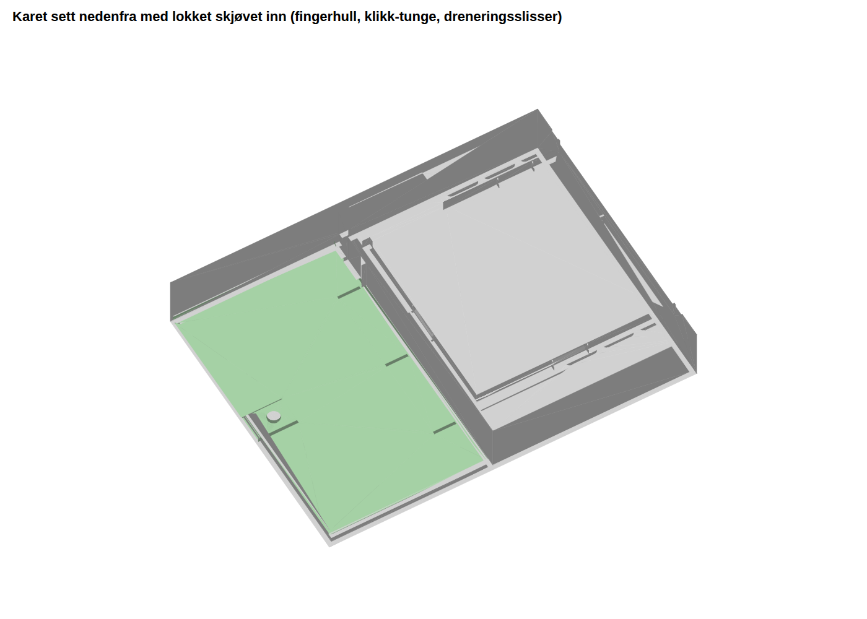
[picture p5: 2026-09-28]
tegninger/v4.3/sluse_v4.3_kar_med_lokk.png

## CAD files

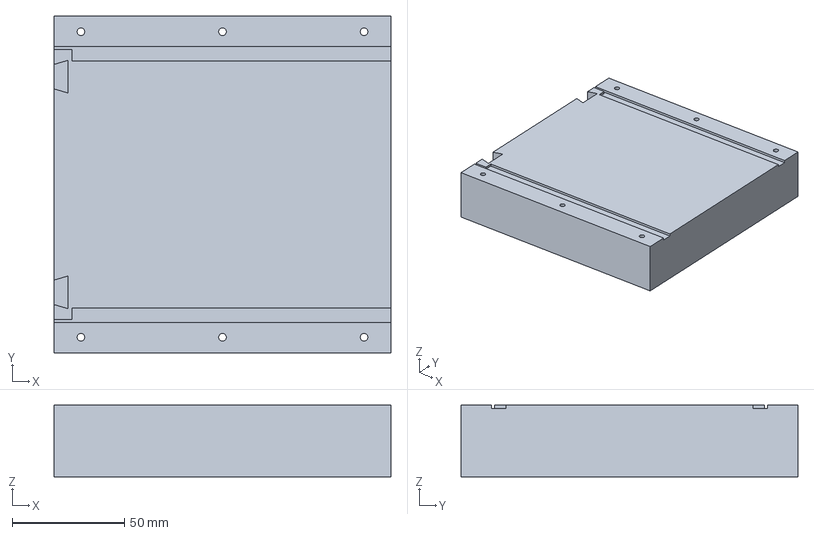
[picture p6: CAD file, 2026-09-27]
step/modul_B/modul_B_kar.step
150.0 x 150.0 x 32.0 mm

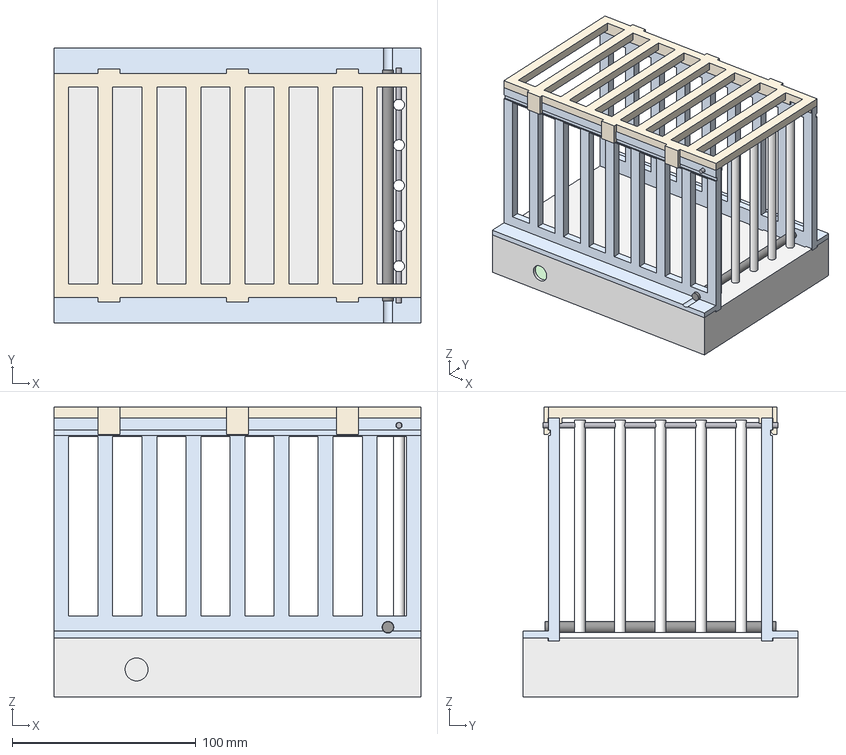
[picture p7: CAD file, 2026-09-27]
step/sluse_MA/sluse_MA_sammenstilling.step
200.0 x 150.0 x 158.0 mm
kar
lokk
vegg_hoyre
vegg_venstre
tak
terskelstang
gaffel_1
gaffel_2
gaffel_3
gaffel_4
gaffel_5
aksel_rustfri_ref
spole_referanse

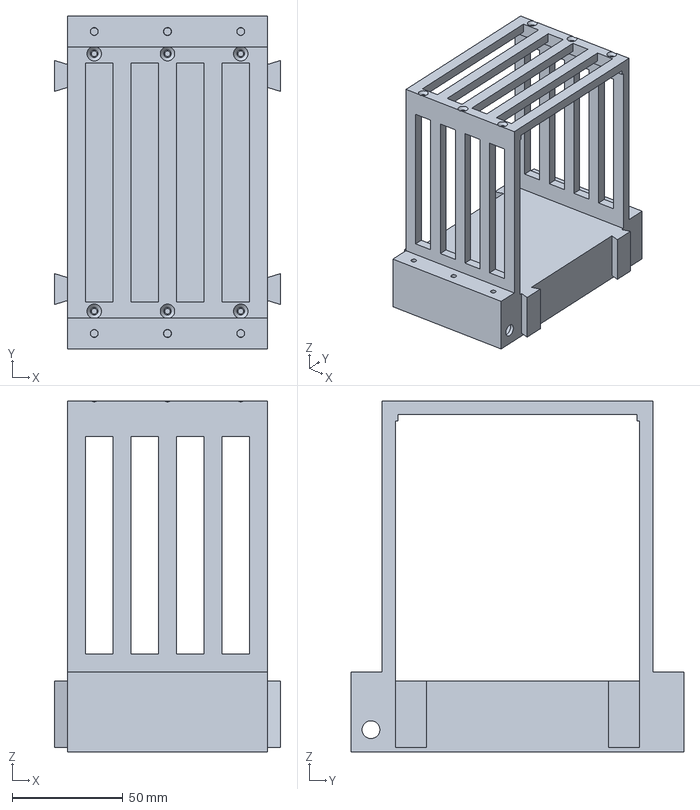
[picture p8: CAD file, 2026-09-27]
step/sluse_v3_modul_M_elektronikk.step
102.0 x 150.0 x 158.0 mm

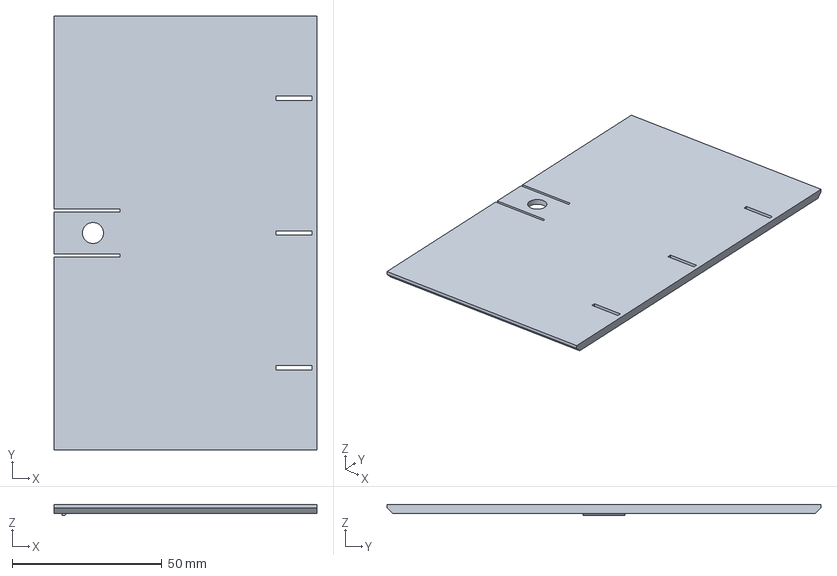
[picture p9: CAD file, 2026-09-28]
step/v4.3/sluse_v4.3_lokk.step
87.7 x 144.6 x 3.80 mm

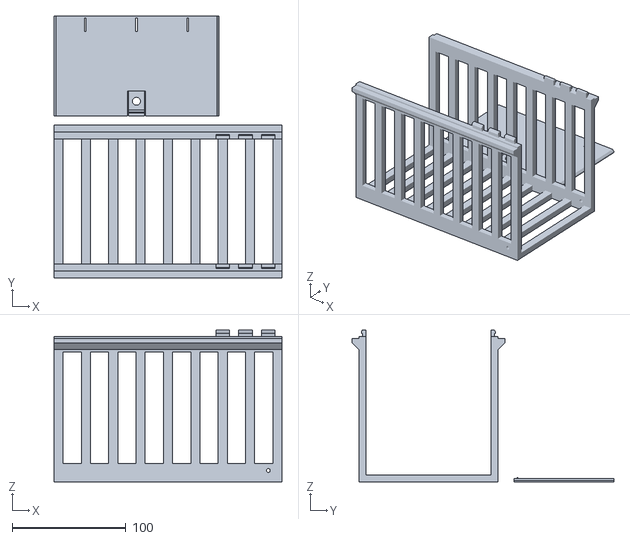
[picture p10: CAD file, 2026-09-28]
stl/v4.3/sluse_v4.3_print2_hette_og_lokk.stl
200.0 x 229.7 x 133.2

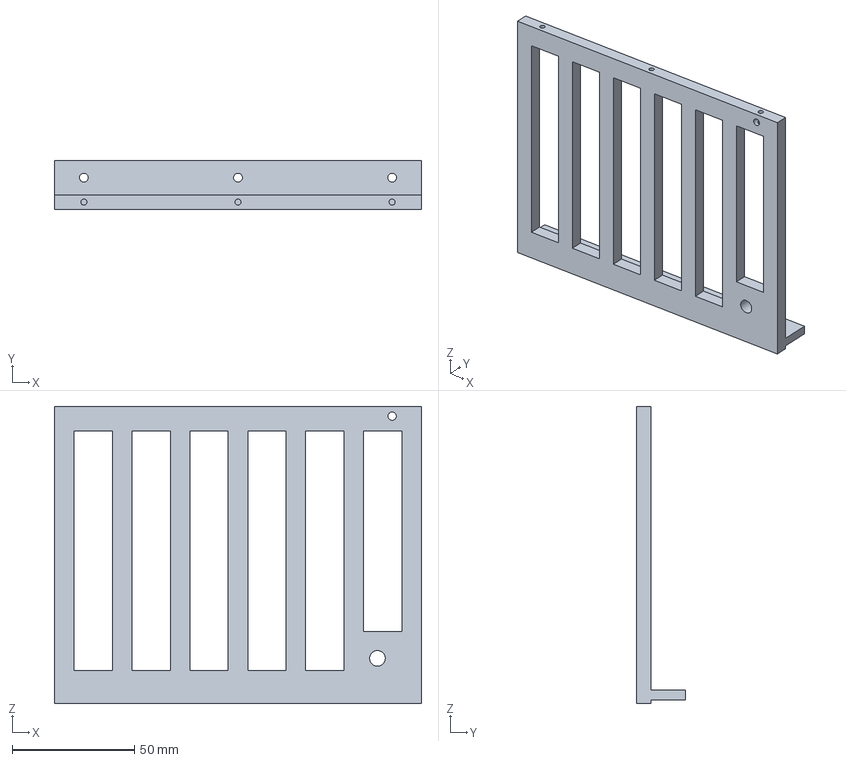
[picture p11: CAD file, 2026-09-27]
step/modul_B/modul_B_vegg_hoyre.step
150.0 x 20.0 x 121.5 mm

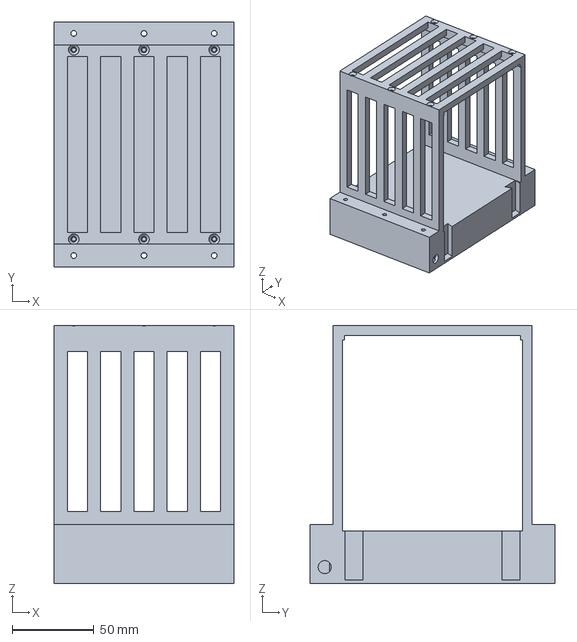
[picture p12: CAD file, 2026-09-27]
step/sluse_v3_modul_A_rett_spole.step
110.0 x 150.0 x 158.0 mm

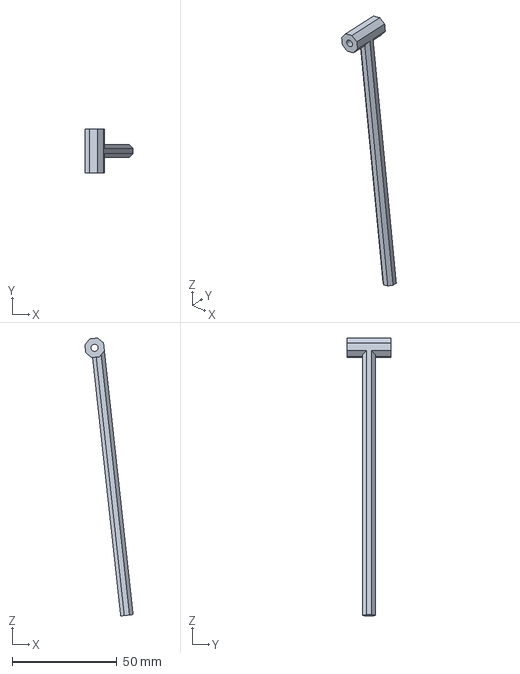
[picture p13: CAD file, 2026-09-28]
step/v4.3/sluse_v4.3_gaffel.step
23.1 x 21.0 x 132.7 mm

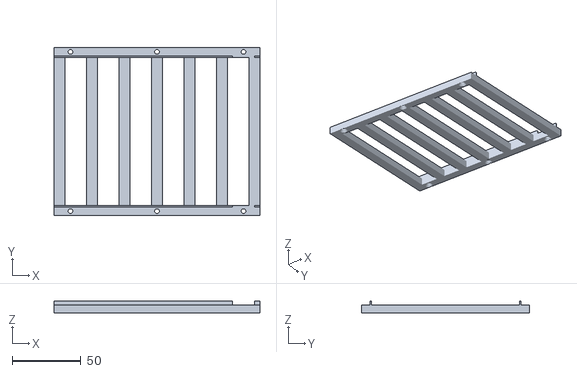
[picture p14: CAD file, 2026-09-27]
stl/modul_B/duesluse_modul_B_tak.stl
150.0 x 122.0 x 9.00

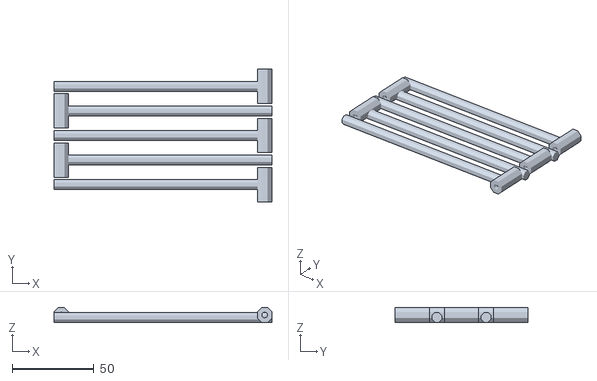
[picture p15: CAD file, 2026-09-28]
stl/v4.3/sluse_v4.3_gafler.stl
133.1 x 81.0 x 9.00

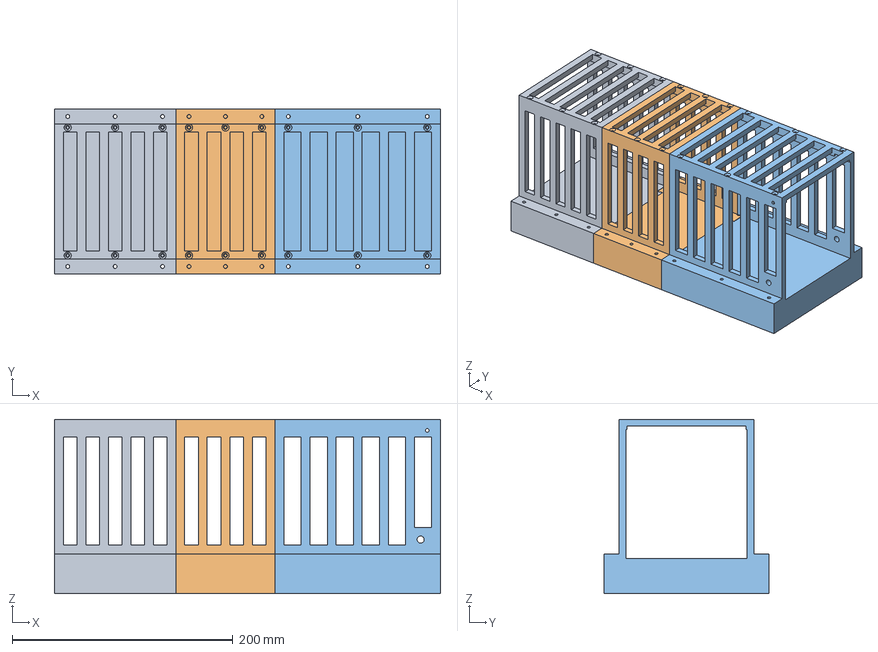
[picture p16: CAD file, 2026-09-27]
step/sluse_v3_komplett_3_bodies.step
350.0 x 150.0 x 158.0 mm

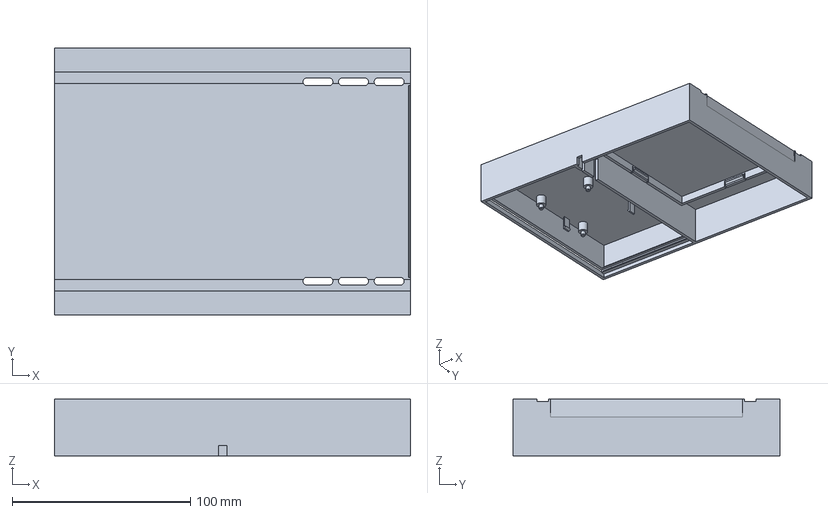
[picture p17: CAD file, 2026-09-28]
step/v4.3/sluse_v4.3_kar.step
200.0 x 150.0 x 32.0 mm

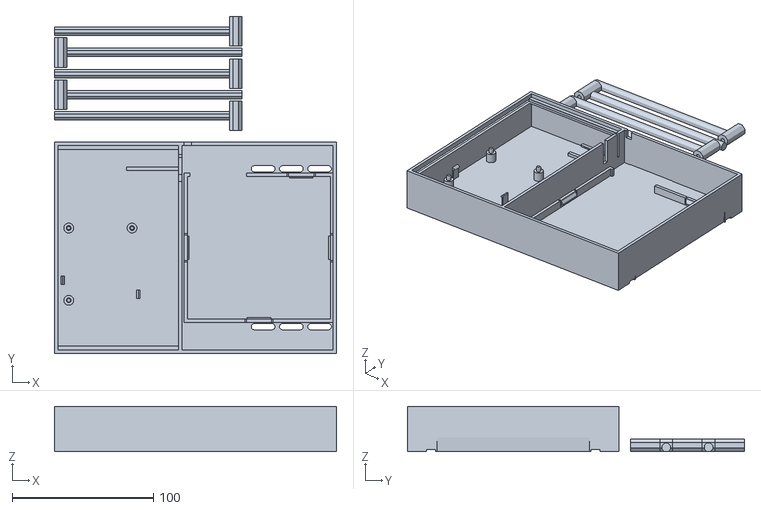
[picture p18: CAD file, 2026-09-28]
stl/v4.3/sluse_v4.3_print1_kar_og_gafler.stl
200.0 x 239.0 x 32.0

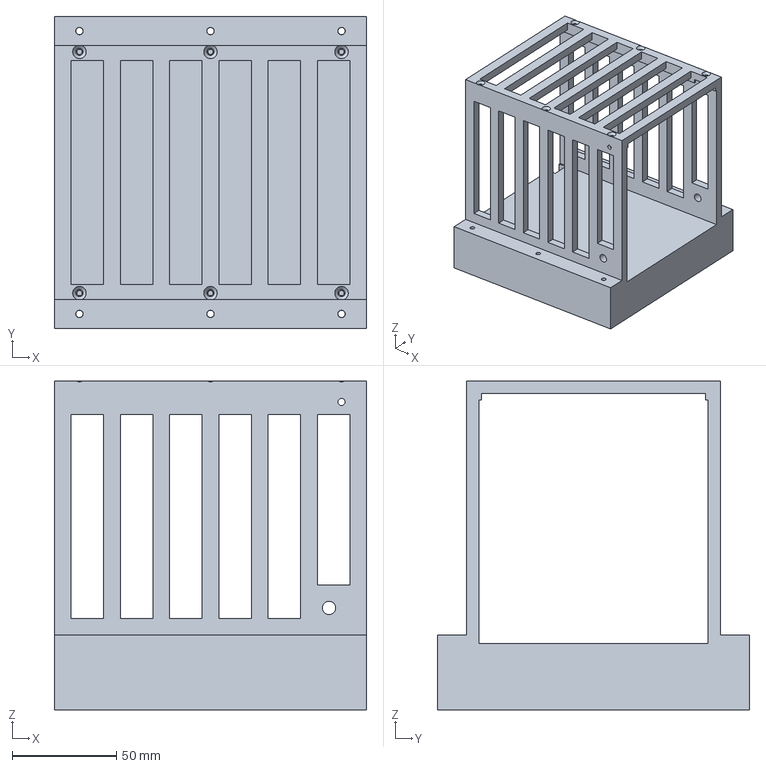
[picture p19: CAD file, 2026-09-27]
step/sluse_v3_modul_B_diamant.step
150.0 x 150.0 x 158.0 mm

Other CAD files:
stl/modul_B/duesluse_modul_B_kar.stl
step/modul_B/modul_B_vegg_venstre.step
stl/modul_B/duesluse_modul_B_vegg_hoyre.stl
step/modul_B/modul_B_tak.step
step/modul_B/modul_B_sammenstilling.step
step/v4.1/sluse_v4.1_hette.step
step/v4.1/sluse_v4.1_kar.step
step/v4.1/sluse_v4.1_lokk.step
step/v4.1/sluse_v4.1_sammenstilling.step
step/v4.1/sluse_v4.1_terskelstang.step
step/v4.2/sluse_v4.2_hette.step
step/v4.2/sluse_v4.2_kar.step
step/v4.2/sluse_v4.2_lokk.step
step/v4.2/sluse_v4.2_sammenstilling.step
step/v4.3/sluse_v4.3_hette.step
step/v4.3/sluse_v4.3_sammenstilling.step
step/v4/sluse_v4_kar.step
step/v4/sluse_v4_lokk.step
step/v4/sluse_v4_sammenstilling.step
step/v4/sluse_v4_tak.step
step/v4/sluse_v4_terskelstang.step
step/v4/sluse_v4_vegg_hoyre.step
step/v4/sluse_v4_vegg_venstre.step
stl/modul_B/duesluse_modul_B_vegg_venstre.stl
stl/v4.1/sluse_v4.1_gafler_og_terskel.stl
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

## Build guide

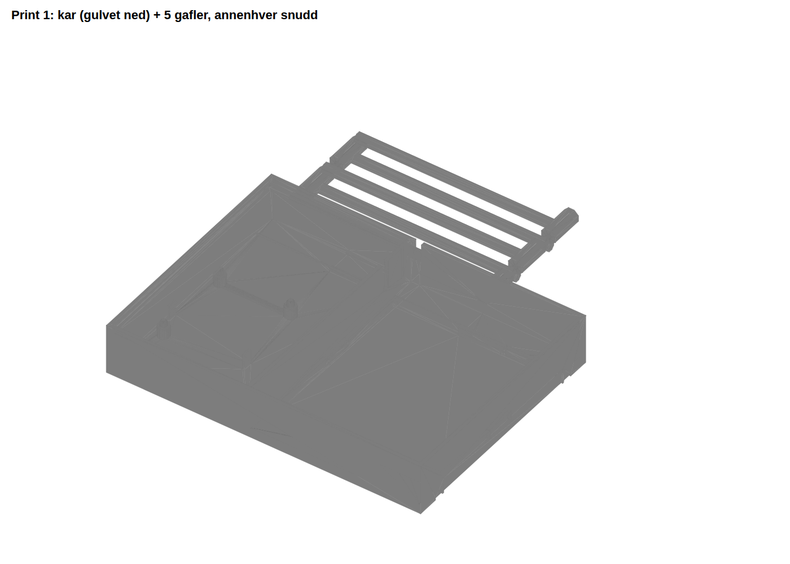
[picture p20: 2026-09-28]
tegninger/v4.3/sluse_v4.3_print1.png

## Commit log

2026-09-27 Første versjon: modulær duesluse med RFID-spoler
    - Modul B (diamantspole): kar, veggpanel høyre/venstre og takpanel som STL,
    lagt i print-orientering for Bambu A1 (PETG, ingen støtte)
    - Generatorskript (manifold3d) med alle mål som parametre
    - Tekniske tegninger v1–v3 (SVG/PNG) med generatorskript
    - Analyse av spolehøyde og lesesikkerhet, med Biot–Savart-modell
    Claude-Session: https://claude.ai/code/session_01SQyqCU3WJ7Qa2nHFEGXUhT
    [duesluse_modul_B_kar.stl, duesluse_modul_B_tak.stl, duesluse_modul_B_vegg_hoyre.stl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]
2026-09-27 Legg til STEP-filer: hele v3 med tre bodies og modul B per del
    - step/sluse_v3_komplett_3_bodies.step: modul A, M og B som hver sin body
    (kar + vegger + tak), montert posisjon, svalehalene uten overlapp
    - step/sluse_v3_modul_*.step: én modul per fil
    - step/modul_B/: kar, vegg høyre/venstre, tak og sammenstilling som STEP
    (samme geometri og volum som STL-ene)
    - generator/sluse_v3_step.py og generator/modul_B_step.py (CadQuery)
    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
    [modul_B_kar.step, modul_B_sammenstilling.step, modul_B_tak.step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]
2026-09-27 Sluse M+A: ett kar med forgang, rett spole, gafler og klikk-feste
    - Kar 200 x 150: elektronikkammer (lokk m/ pakning fra undersiden) som
    forgang, rett 10x10-spole i lomme med fire klikk-neser (ingen ribber i veien)
    - Vegger klikkes fast med tapper ned gjennom gulvet i spoledelen,
    tak klikkes inn i spor på utsiden av veggene – ingen skruer
    - Gafler Ø6 x 116 til 3 mm over gulvet mot terskelstang på slusesiden
    - STL i print-orientering (ingen støtte) og STEP montert + per del
    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
    [sluse_MA_gafler_og_terskel.stl, sluse_MA_kar.step, sluse_MA_kar.stl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]
2026-09-27 v4: gi M+A-slusa eget versjonsnavn
    Samme modell som forrige commit, nå tydelig merket som v4:
    - stl/sluse_MA -> stl/v4, step/sluse_MA -> step/v4,
    tegninger/sluse_MA -> tegninger/v4, filer omdøpt til sluse_v4_*
    - generator/sluse_MA_step.py -> generator/sluse_v4_step.py
    (lager byte-identiske STL-er under de nye navnene)
    - README: versjonsoversikt v1–v4, v4 som gjeldende modell,
    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
    [sluse_v4_gafler_og_terskel.stl, sluse_v4_kar.step, sluse_v4_kar.stl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]
2026-09-27 v4.1: vegger og tak som én hette – to print totalt
    Kar, lokk og gafler er uendret fra v4. Hetta printes opp-ned (taket på
    platen), veggfot 12 mm med 45° skråkant, klikket mellom tak og vegg er fjernet.
    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
    [sluse_v4.1_gafler_og_terskel.stl, sluse_v4.1_hette.step, sluse_v4.1_hette.stl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]
2026-09-27 v4.2: 8-kantede gafler som hviler mot karkanten, uten terskelstang
    Akselen står der den var. Gaflene henger ca. 7° på skrå og ligger mot en
    skråflate i karets endekant (10 mm ned). Terskelstangen er fjernet.
    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
    [sluse_v4.2_gafler.stl, sluse_v4.2_hette.step, sluse_v4.2_hette.stl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]
2026-09-28 v4.3: kabelføring, kortfeste, skyvelokk løftet 4 mm, leser i tørt rom, gafler med nav
    - Lokket skyves inn fra inngangen i 45°-spor, klikk-tunge, fingerhull og drenering.
    - Leserholder i hjørnet ved skilleveggen; 2 mm sprekk for spoletråder og 5 mm slisse
    for strømkabel i skilleveggen, slisse i underkant av sideveggen. PG7-hull fjernet.
    - PigeonPal-PCB på tre styretapper (H1, H3, H4) og to fjærende kroker.
    - Gafler med 21 mm 8-kantet nav som holder avstanden. Ribbene og det blinde hullet fjernet.
    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
    [sluse_v4.3_gaffel.step, sluse_v4.3_gafler.stl, sluse_v4.3_hette.step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]
2026-10-16 v5: skuff-lokk uten lange spor, kroker og trykknapper for hetta, tak som flygende due, dobbel spileavstand
    Printproblemene i v4.3 (145 mm bro under lokkspalten, veggtapper med ca. 8 % tøyning
    på tvers av lagene, renner og slisser i første lag) løses ved å legge alle fjærer i
    printplanet med tøyning under 1 %, åpne endeveggen under lokket, korte kiler/stoppere,
    L-kroker ved inngangen og fjærbjelker i karets endevegg ved slaget. Generator, STEP,
    STL, render-skript og README.
2026-10-16 v6: ett stykke etter Stigs sluse, forgang med el-rom under gulvet, spole i lomme, skuff fra siden
    Utgangspunkt er Stigs Fusion-modell «nyeste antenne løsning» (lagt i stl/v5/).
    Gulvplate 212 × 128 løftet 32 mm, forgang 88 mm med el-rom under, fire ribber og to
    portaler med spiss døråpning (38°), toppramme langs begge sider, spiss topp i alle
    mellomrom i veggene, spiler i karet, spolelomme med klikk-neser under de siste 100 mm,
    40 mm gulv uten vegger mot slaget. Skuffen skyves inn fra −y med kortsiden først,
    tunge med nese bak veggkanten, hakk for negl, ingen fingerhull. Leserholder 1,5 mm
    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
2026-10-16 Arbeidsregler og arbeidslogg for Slusemodul
    CLAUDE.md: regler fra Stig (branch, ett steg om gangen, OK før endring,
    push bare på beskjed) og designreglene for print (fjærer i planet,
    tøyning under 1 %, ingenting i første lag, ingen støtte).
    ARBEIDSLOGG.md: arbeidsfordeling, status, beslutninger og åpne spørsmål
    per økt, slik KiCad-repoet har det. README beskriver bare modellene.
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
